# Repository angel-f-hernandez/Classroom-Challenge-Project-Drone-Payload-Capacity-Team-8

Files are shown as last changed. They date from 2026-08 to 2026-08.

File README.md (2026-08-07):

# Solution to Classroom Challenge Project Drone Payload Capacity and Structural Design Analysis

# Team
Ray Cillo (UCLA) - Project Manager, Quality Assurance

Angel Hernandez (Cal Poly SLO) - Documentation, Visualization & FEA Lead

Aadesh Bamane (SDSU) - Modeling Lead

Angelina Mikhaiel (SDSU) - Analysis/Validation Lead

# Project Details
In this project, a drone arm was designed and analyzed by calculating the maximum stress of the arm, performing a thrust-to-weight analysis to determine payload capacity, and conducting Finite Element Analysis. In designing the arm, our team first brainstormed simple shapes that could be used. After those shapes were sketched, their area, volume, and density equations were inputted into a MATLAB code, and dimensions were approximated before they were sketched and completed in a CAD software. This allowed us to pick dimensions for each arm that would keep it above our minimum factor of safety of 1.5 while still meeting the 0.5 kg minimum payload and 2:1 thrust-to-weight requirements. Finite element analysis would be completed after the shapes were sketched and designed in a CAD software. The two shapes that our team decided to use in this project are a hollow, oval shaped arm, and a truss inspired arm.

Our first set of dimensions came from the approximate MATLAB calculations, but the finite element analysis showed that those designs did not hold up. The oval arm deformed more than we wanted, and the truss arm fell below the minimum factor of safety for half of the material options, mostly because of stress concentrations at the joints and mounting holes that our simpler equations could not account for. We revised both designs with thicker walls and wider truss members, which fixed both problems but added mass and reduced how much payload the drone could carry.

After completing a MATLAB code to run a stress analysis and finite element analysis on each arm design, the two were compared to determine which design best met the requirements and stayed above the minimum factor of safety. Some of the factors that were considered when determining which design had the best results included which one had a better margin above the required factor of safety, and which one had the higher maximum payload capacity. The finite element analysis was also used to determine which arm design had less stress and displacement. These results can be seen in the graph and data below.

# Project Solution Instructions

**Requirements:** MATLAB R2023b or later with the Partial Differential Equation Toolbox.

1. Place the closed STL or STEP files for each drone-arm design in the `cad` folder.
2. Open `DroneDesign_StudentProjectTemplate.mlx` in MATLAB.
3. Update the `filePaths` string array so that it contains the relative path to each CAD file.
4. Update the `designNames` string array so that each design name corresponds to the CAD file in the same array position.
5. Update the `areas` array using units of square meters. In the current implementation, each value represents the surface area of one loaded face. The code assumes that all loaded faces selected for a design have equal areas, and the function multiplies this value by the number of selected loaded faces.
6. Run Task 1 to load the material properties and initialize the project parameters.
7. Run Task 3 to calculate the volume, arm mass, and maximum payload for each design and material combination.
8. Run the first portion of Task 4 containing `designVisualizer(filePaths)`. Use the displayed face labels to identify the attachment and load surfaces on each model.
9. Update `fixedFaces` with the face IDs of the surfaces attached to the drone body.
10. Update `loadedFaces` with the face IDs of the surfaces where the motor loads are applied.
11. Run the remainder of Task 4 to perform the finite element analyses, generate the displacement and von Mises stress plots, calculate the factor of safety, and create the final results table.
12. Review the results and confirm that the selected design:
* supports a payload of at least 0.5 kg,
* maintains a thrust-to-weight ratio of at least 2:1, and
* has a factor of safety of at least 1.5.
# Results
## Summary of Payload and FEA Results
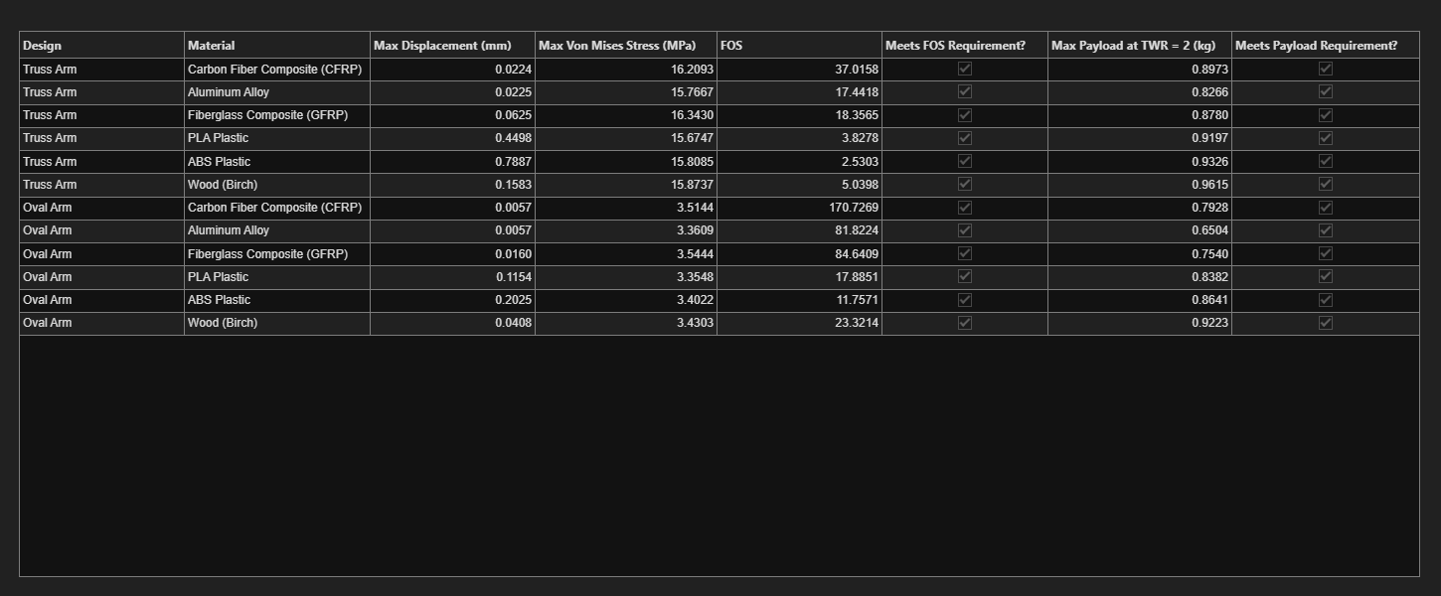
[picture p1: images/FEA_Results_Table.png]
Final table of results (task 4)


## Carbon Fiber Composite Planar Truss: Displacement and Von Mises Stress
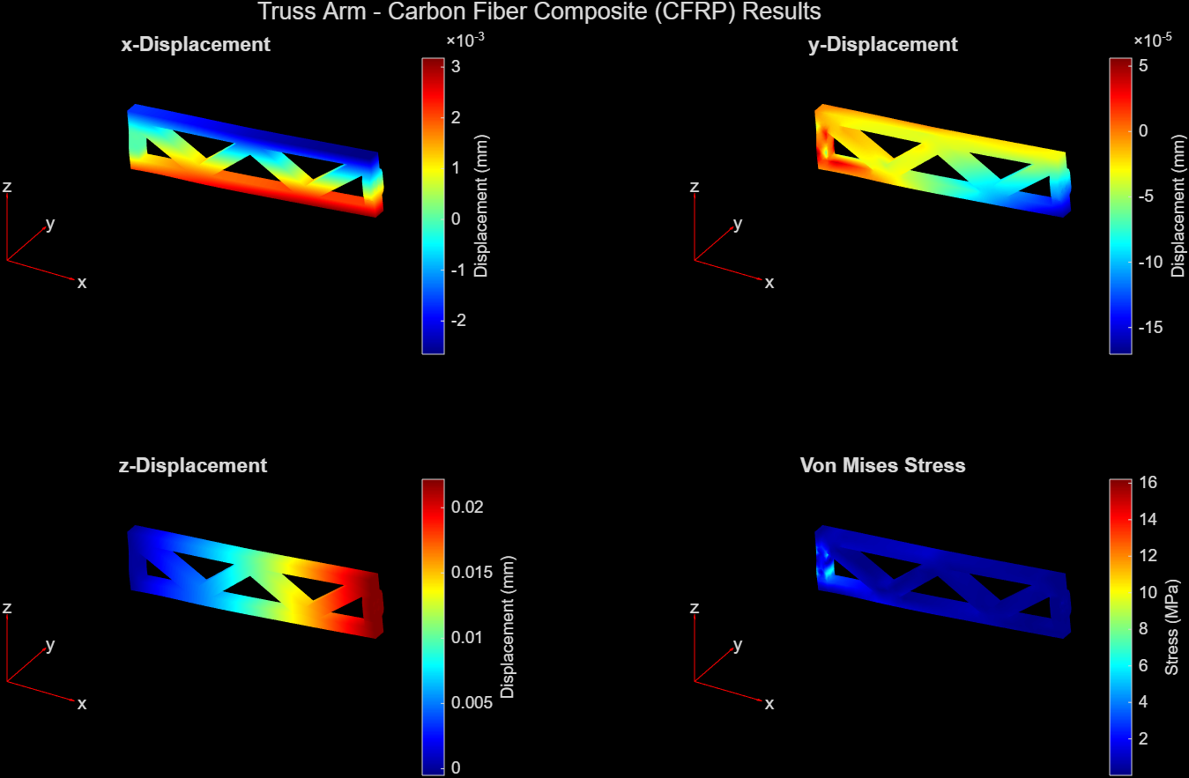
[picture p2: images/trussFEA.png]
FEA of truss (Carbon fiber)


## Carbon Fiber Composite Hollow Oval Arm: Displacement and Von Mises Stress
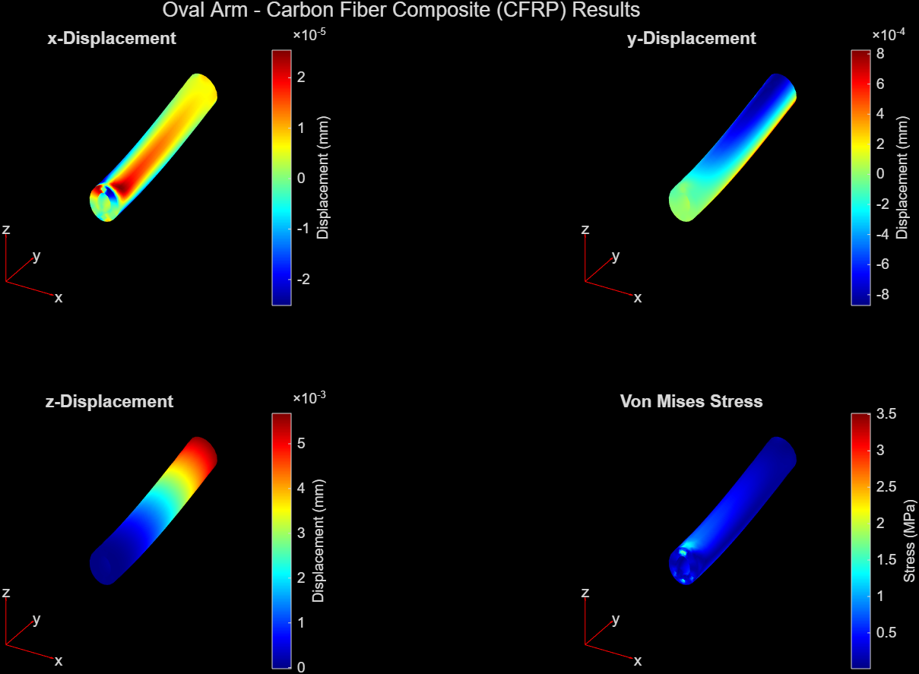
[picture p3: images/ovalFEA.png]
FEA of hollow oval (Carbon fiber)


# Final Recommendation

The recommended design is the planar truss arm made from carbon fiber composite. This combination supports a maximum payload of 0.8973 kg while limiting maximum displacement to approximately 0.0224 mm and maintaining a factor of safety above the required minimum of 1.5.

Although several lower-density materials provided slightly higher maximum payload capacities, they also experienced greater displacement. The carbon fiber truss therefore provided the best overall balance between payload capacity, stiffness, mass efficiency, and structural safety.
# Contact
raynittacillo@gmail.com

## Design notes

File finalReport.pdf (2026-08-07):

## Drone Payload Structure Design and Analysis

In this project, you are optimizing drone arm design, including geometry and material selection, to maximize payload capacity while ensuring structural integrity under motor-induced loads. You will use MATLAB to perform force balance analysis and finite element modeling to quantitatively support your design solution.

Use this Live Script as a template to get started on your project solution. You may include helper functions at the bottom of this document or as separate files. For a tutorial on how to use Live Scripts, check out this video. (https://www.youtube.com/watch?v=hUXTyPYRidM)

Suggested Tasks

1. Gather your starter assumptions and load the material properties into MATLAB.
2. Propose at least two drone arm designs
3. Perform a thrust-to-weight analysis to evaluate each of your designs across all material options. Your design must meet a minimum payload requirement and safety standards.
4. Perform finite element analysis across all design and material options.
5. Recommend a final design solution.

Table of Contents

## Break Down the Problem

In the space below, define the problem statement:

The goal is to design a drone arm that can safely handle motor-induced loads while maximizing payload capacity. Two structurally distinct designs must be created and analyzed using finite element analysis (FEA), thrust-to-weight analysis, and provided drone arm material properties. The designs must meet project-specified minimum payload and thrust-to-weight ratio requirements, as well as a minimum factor of safety (FOS) requirement to ensure safe operation.

List the requirements, constraints, and success criteria for the project:

Requirements:

- Minimum payload requirement: 0.5 kg
- Minimum thrust-to-weight ratio: 2:1
- Minimum FOS: 1.5

Constraints:

- Quadcopter configuration: 4 motors and 4 propellers
- Motor mass: 0.065 kg per motor
- Thrust per motor: 1 kg of thrust
- Maximum total thrust: 4 kg of thrust
- Maximum drone arm mass: 0.125 kg per arm
- Total mass of components excluding drone arms and payload: 1.0 kg

Success Criteria:

1. Drone arm must maximize payload capacity while meeting minimum thrust-to-weight ratio and minimum FOS.
2. Drone arm must minimize mass.
3. Drone arm must limit maximum stress and displacement.
4. Drone arm should minimize material cost (optional).

What is your proposed solution?

We propose two possible drone arms. The first drone arm design will use a hollow oval cross-section
and one drone body attachment points. The second drone arm will use a triangular truss design and contain three drone body attachment points, and the truss design will contain solid outer supports and solid inner web members.

List the steps you will need to take to achieve your proposed solution:

1. Sketch out two drone arms, making sure to include rough dimensions, a motor attachment point, and drone body attachment point(s).
2. Create the 3D models from sketches using CAD software. Export these models as STL for analysis.
3. Analyze both drone arms and provide initial thrust-to-weight ratio results for each drone arm and material combination.
4. Perform FEA on the drone arms and record x-, y-, and z- displacement as well as Von Mises stress. Ensure drone arms meet the minimum FOS.
5. Use an optimization function that minimizes mass and material cost (optional).
6. Display required results. This includes thrust-to-weight and FEA results for each drone arm and material combination.
7. Analyze the FEA data and compare the advantages/disadvantages of each drone arm. Comparison should include payload capacity, arm mass, FOS, Von Mises stress, and displacement differences.
a. Optional: Include material cost comparison.
8. Submit our final report which includes a drone arm design recommendation.

What challenges do you face in the process of achieving the solution?

1. Material selection and tradeoff analysis: Each material has different properties that give it distinct advantages and disadvantages. The challenge arises from selecting a material with advantageous properties that align with the drone arm requirements while minimizing disadvantageous properties.
2. Drone arm design and CAD: The dimensions of the drone arm affect mass, stress, and displacement, which makes dimension selection a vital part of the drone design process. Additionally, the selected dimensions must be realistic to ensure that the drone arm can be manufactured. Due to the team's limited experience in design, the selection of proper dimensions is a challenge.
3. FEA setup: The team members have limited experience with FEA. As a result, properly setting up FEA in MATLAB and accurately interpreting results becomes a challenge.

## Task 1: Gather your starter assumptions and load material properties

Load the provided droneArmMaterials.mat file into MATLAB. This contains a data struct with the material properties for six different materials commonly used for drones (carbon fiber composite, aluminum alloy, fiberglass composite, PLA plastic, ABS plastic, and wood). For each material, you have been provided the following information:

▪
Density ( ), in
- Young's Modulus (E) in Pa
- Poisson's ratio ( ), unitless
- Yield strength, in Pa
- Average cost per meter in US dollars

For this project, you can assume the following design parameters:

- Quadcopter drone with 4 motors and 4 propellers
- Each motor can provide up to 1kg thrust
▪
Acceleration due to gravity:
- Total weight of the drone components without the arms or the payload: 1kg

The breakdown of the weight of each drone component is as follow:

- Battery = 0.3kg
- Each motor = 65g, 4 motors = 0.26kg
- Each propeller = 10g, 4 propellers = 0.04 kg
- Each electronic speed controller = 30g, 4 electronic speed controllers = 0.12 kg
- Flight controller and electronics = 0.05kg
- Receiver/GPS = 0.03kg
- Drone frame (center body) excluding arms = 0.2kg

clear, clc, close all
addpath('functions');
materials = importdata("data\droneArmMaterials.mat");

% Assign file paths for drone arm files filePaths = [
"cad/TrussArm.step"
"cad/OvalArm.step"
];
designNames = [
"Truss Arm"
"Oval Arm"
];
areas = [[0.00002827, 0.00002827]]; % m^2

% Arrays of material data

[materialNames, density, youngsModulus, poissonsRatio, yieldStrength, cost] = materialDataExtractor(materials);
nMaterials = numel(materials);
g = 9.81; | % gravitational acceleration [m/s^2]
nMotors = 4; | % number of motors
nProps = 4; | % number of propellers
nArms = 4; | % number of arms

thrustPerMotor_kg = 1;
maxTotalThrust_kg = nMotors * thrustPerMotor_kg;
mBattery = 0.30; | % battery [kg]
mMotors = nMotors * 0.065; % 4 motors, 65 g [kg]
mProps = nProps * 0.010; | % 4 propellers, 10 g [kg]
mEsc = 4 * 0.030; | % 4 ESCs, 30 g [kg]
mFlightCtrl = 0.05; | % flight controller + electronics [kg]
mReceiverGPS = 0.03; | % receiver / GPS [kg]
mFrame = 0.20; | % center body, excludes arms [kg]

baseMass = mBattery + mMotors + mProps + mEsc + mFlightCtrl + mReceiverGPS + mFrame;

motorMass = 0.065; % [kg]

minPayload = 0.5; | % minimum required payload [kg]
minTWR = 2; | % minimum thrust-to-weight ratio
minFOS = 1.5; | % minimum factor of safety

% Net transverse tip load for the Task 3 stress pre-screen [N] thrustPerMotor_N = thrustPerMotor_kg * g;
motorWeight_N = motorMass * g;
F_tip_N = thrustPerMotor_N - motorWeight_N; | % net upward load bending the arm
FOSmin_preFEA = 2.0; | % FOS accounting for hand calculation
errors

## Task 2: Propose at least two drone arm designs

Develop at least two distinct drone arm designs by drawing clear, neatly labeled sketches that show key geometric features, including:

- Overall shape (e.g. beam, tube, truss structure)
- Dimensions (length, width, thickness)
- Motor mount location
- Where the arm connects to the drone body

The two designs should be meaningfully different from each other (e.g. different geometries or structural strategies) and not just small variations of the same idea.

Navigate to the 'Insert' tab and insert pictures of your sketches in the space below (hand-drawn or digital). Include a short design description for each sketch that includes:

- Geometry (e.g. solid beam, hollow tube, beam with trusses)
- Why you chose this design
- How it might perform under load

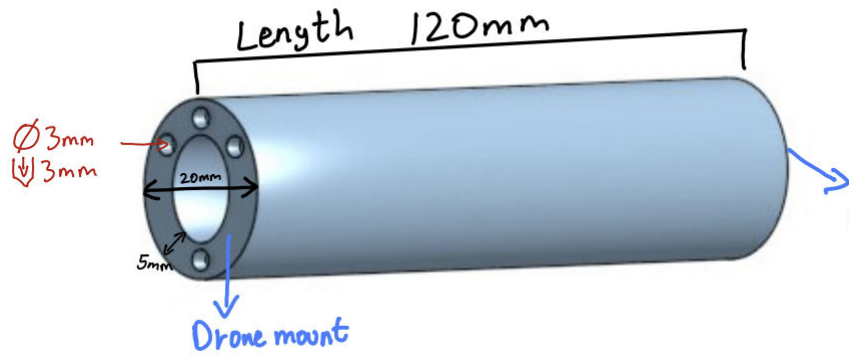
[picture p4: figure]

Design 1 — Hollow Oval Tube

Geometry: Hollow oval tube, 120 mm long, 25 mm tall × 20 mm wide outer cross-section with a 5 mm uniform wall (15 × 10 mm inner bore). Motor mounts at the tip via four Ø3 mm × 3 mm holes; the arm bolts to the drone body at the base end through a matching four-hole pattern.

Why we chose it: A closed section distributes bending load around the full perimeter and resists torsion from motor and propeller reaction, which an open section cannot. Hollowing the center removes material near the neutral axis, where bending stress is lowest, so very little strength is given up for the weight saved. The section is taller than it is wide because section depth is cubed in the second moment of area while width contributes only linearly, so the tall orientation resists bending far better at the same mass.

How it performs under load: Acts as a cantilever beam, with stress peaking at the top and bottom outer surfaces where the arm meets the body. Our initial design used a thinner wall, but FEA showed excessive tip deflection, which we judged too flexible for stable flight. Increasing the wall to 5 mm brought deflection down substantially at the cost of additional mass.

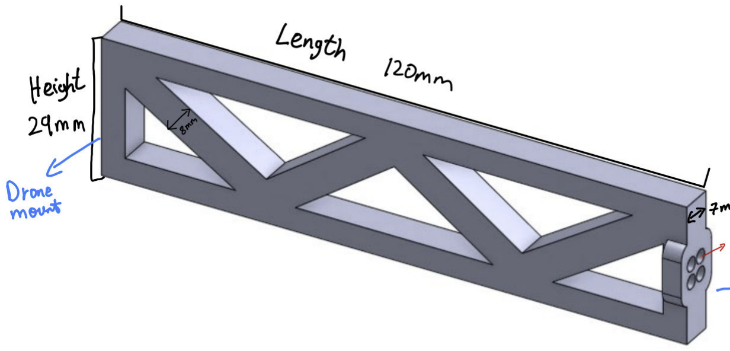
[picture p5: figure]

Design 2 — Planar Truss

Geometry: Flat truss plate, 120 mm long, 29 mm tall, 7 mm thick, with 8 mm wide members forming triangular bays. Motor mounts at the tip through four Ø3 mm × 3 mm holes in a raised boss; the base end attaches to the drone body across the full-height end face.

Why we chose it: Inspired by bridge trusses, which achieve high strength per unit weight. The triangular pattern removes material from regions carrying little load while keeping material along the top and bottom edges where bending demand is highest, so the arm occupies a large structural envelope while using far less material than a solid beam of the same size.

How it performs under load: Bending is resolved into a tension–compression couple in the top and bottom chords, with the diagonals carrying shear between them. Our initial design used 3 mm members, but FEA showed factor of safety below the 1.5 requirement for several material options, driven by stress concentrations at the joints that our analytical model did not capture. Widening the members to 8 mm resolved this across all six materials.

## Task 3: Perform thrust-to-weight analysis across all design and material options

Write a MATLAB function that will perform a thrust-to-weight analysis across all design and material options. This analysis will help you evaluate which drone arm design and which material optimizes payload capacity while meeting suggested safety requirements.

- Your design must support a minimum payload of 0.5kg.
- Your design must meet a thrust-to-weight ratio of at least 2:1 to ensure safe and stable flight. This safety standard is widely used in drone design. Conceptually, it means that the drone's maximum thrust must be at least twice its weight. This ensures stable hovering and maneuvering with a safety margin. Note that the thrust-to-weight safety margin is a system-level safety standard for drone flight that is distinct from the structural safety factor of the drone arms (which you will evaluate later through finite element analysis).
- Your goal is calculate maximum payload capacity for each design and material option (i.e. what is the heaviest payload your drone design could carry while still allowing the drone to safely take off?)

Ensure that the results of your analysis can be readily interpreted, e.g. in the form of a summary table or plot.

Note: if you have two drone arm designs, the expected output should be 12 payload capacity estimates (2 designs across 6 materials options).

% Calculate the volumes of each design (m^3 * kg/m^3)
volumes = calculateDesignVolume(filePaths);

% calculate the mass for each combination of material and design
armMass = density * volumes; | % kg
totalArmMass = armMass .* nArms; | % kg

% calculate max allowed mass and total mass
maxAllowedMass = maxTotalThrust_kg / minTWR; | % kg
totalMass = totalArmMass + baseMass; | % kg

% Calculate max payload
maxPayload = maxAllowedMass - totalMass; | % kg

% Check to see if material and design combination meets the requirements meetsRequirementMinPayload = maxPayload >= minPayload;

## Task 4: Perform finite element analysis across all design and material options

Perform finite element analysis (FEA) across all design and material options to evaluate the structural safety factor of your drone arm design. To simplify the task, you will perform the FEA only on a single drone arm.

Using a CAD software of your choice, first create a 3D model of one drone arm for each of your designs. Be sure your model can be exported as a STEP or STL file for analysis in MATLAB.

- Recommended CAD software options: Tinkercad, Onshape, Fusion 360, Solidworks (most have free versions)

Import your model into MATLAB and perform FEA. In your FEA model, you should model and apply two loads to the drone arm: upward thrust force from the motor and downward weight of the motor.

- Helpful resources: online tutorial, (https://matlabacademy.mathworks.com/details/introduction-to-finite-element-analysis-with-matlab/otmlfea) documentation for Structural Mechanics (https://www.mathworks.com/help/pde/structural-mechanics.html) and Partial Differentiation Equation Toolbox, (https://www.mathworks.com/help/pde/index.html?s_tid=CRUX_lftnav) and example workflow (https://www.mathworks.com/help/pde/ug/deflection-analysis-of-bracket-femodel.html)

For each design and material combination, you should report the overall maximum displacement, maximum stress, and factor of safety and include visualizations of the x-, y-, and z-displacement and Von Mises stress. Ensure that your results are presented for easy interpretation (e.g. present a table with numerical results, clearly labeled subplots for the visualizations).

- The factor of safety compares how strong a material is to how much stress it experiences, indicating whether
a design is safe under the given loads. For this project use the equation: | .

Yield strength indicates how much stress a given material can withstand before permanently deforming. Maximum von Mises stress (derived from your FEA model) is a measure of how much stress your design experiences under the applied loads.
- A typical engineering safety margin for FoS is ~1.5-2+
- This example (https://www.mathworks.com/help/pde/ug/deflection-analysis-of-bracket-femodel.html) demonstrates the plots you are asked to include in your results

% Runs design visualizer to determine which faces a re fixed and loaded designVisualizer(filePaths)

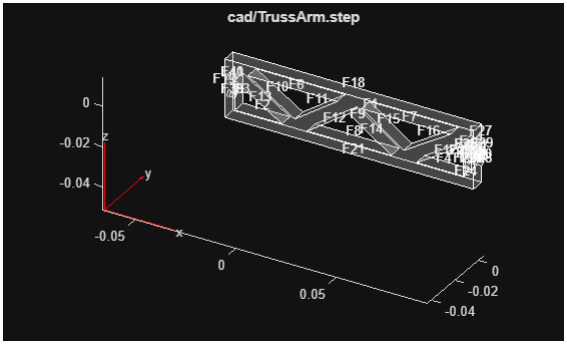
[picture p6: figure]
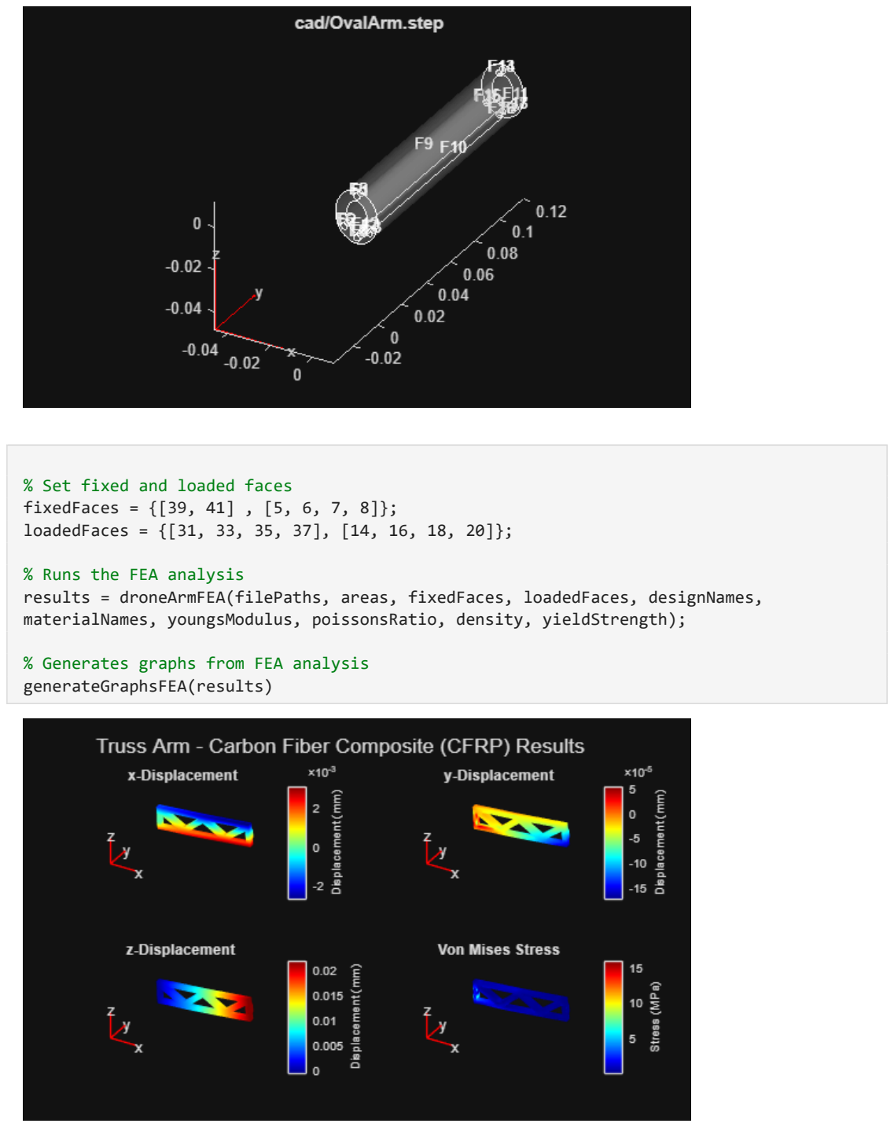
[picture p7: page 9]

% Set fixed and loaded faces
fixedFaces = {[39, 41] , [5, 6, 7, 8]};
loadedFaces = {[31, 33, 35, 37], [14, 16, 18, 20]};

% Runs the FEA analysis
results = droneArmFEA(filePaths, areas, fixedFaces, loadedFaces, designNames, materialNames, youngsModulus, poissonsRatio, density, yieldStrength);

% Generates graphs from FEA analysis
generateGraphsFEA(results)

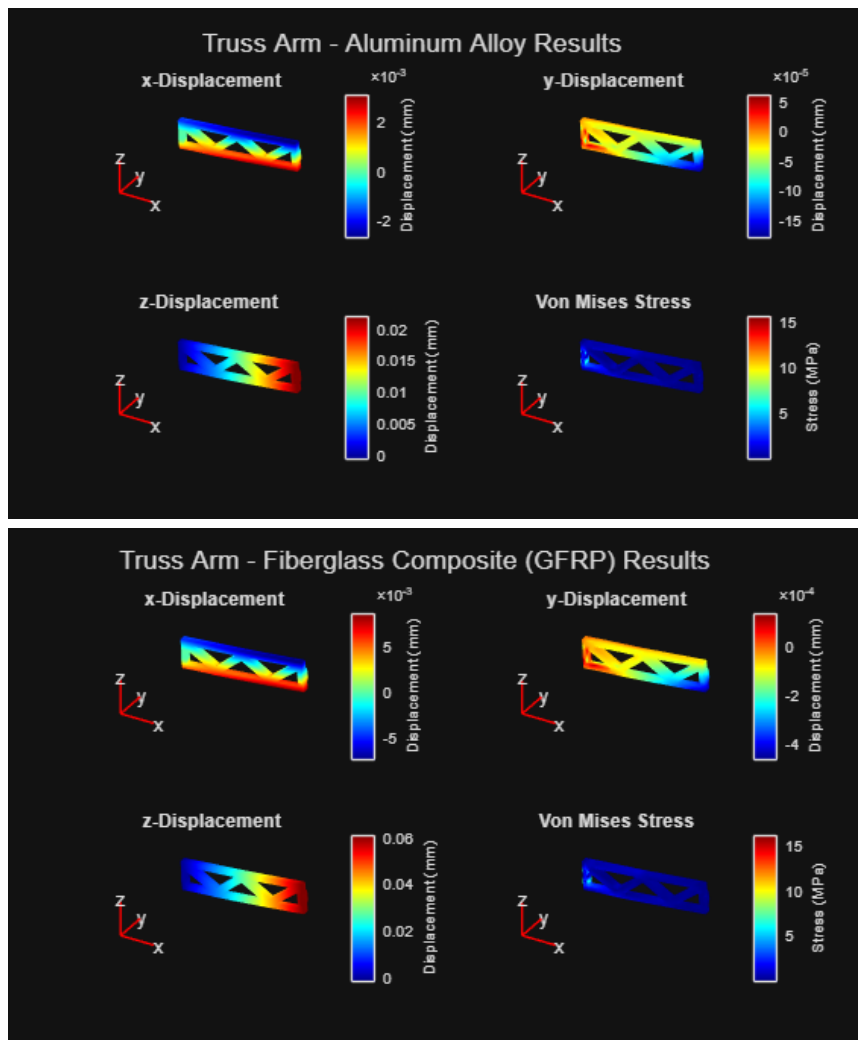
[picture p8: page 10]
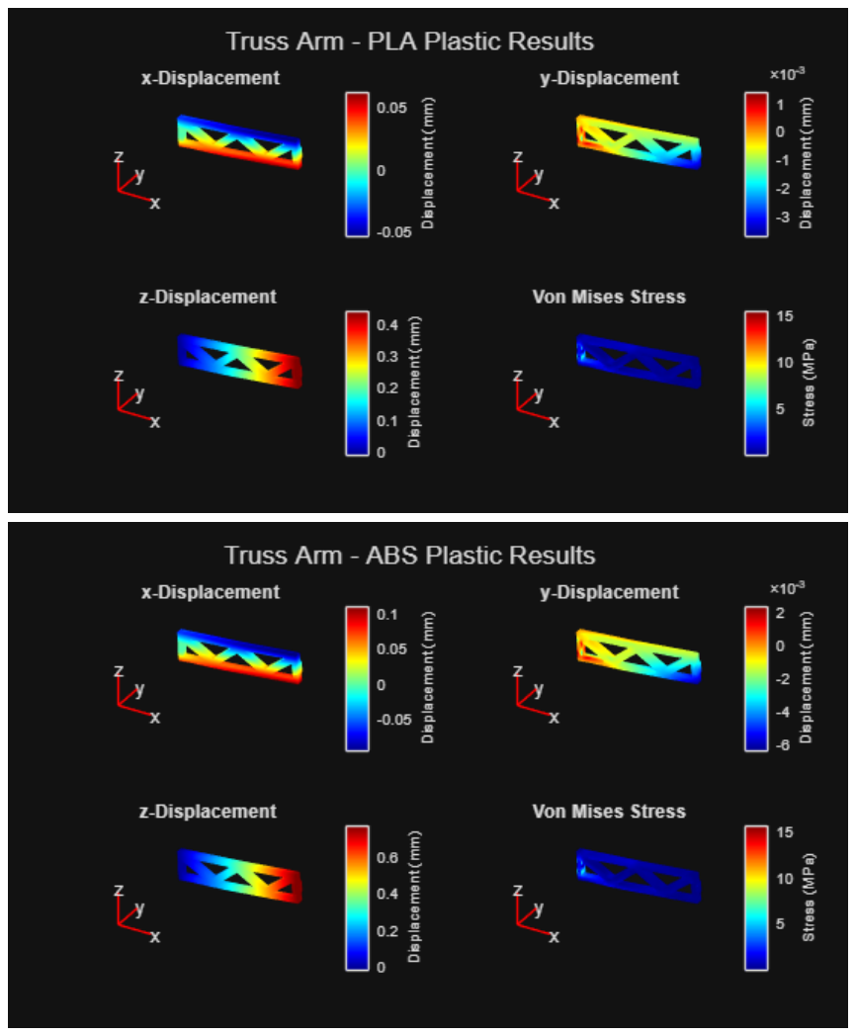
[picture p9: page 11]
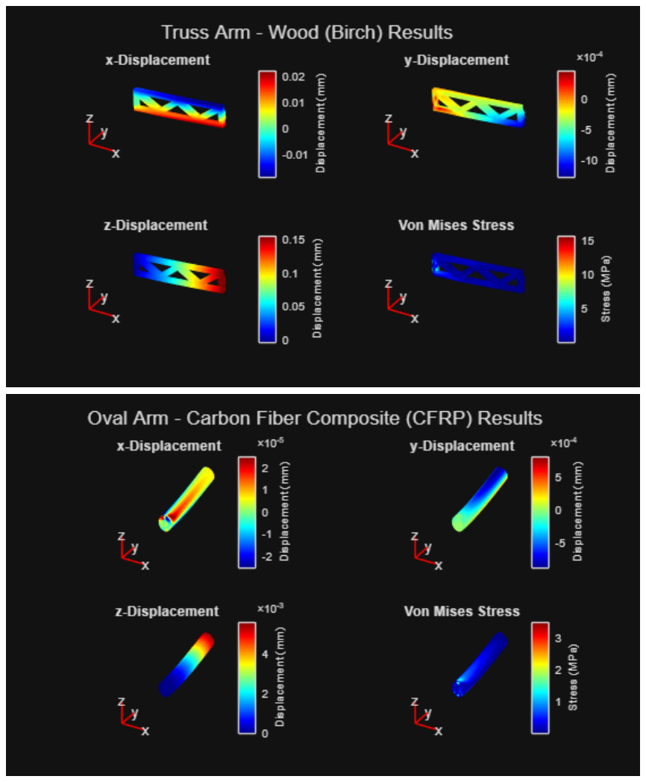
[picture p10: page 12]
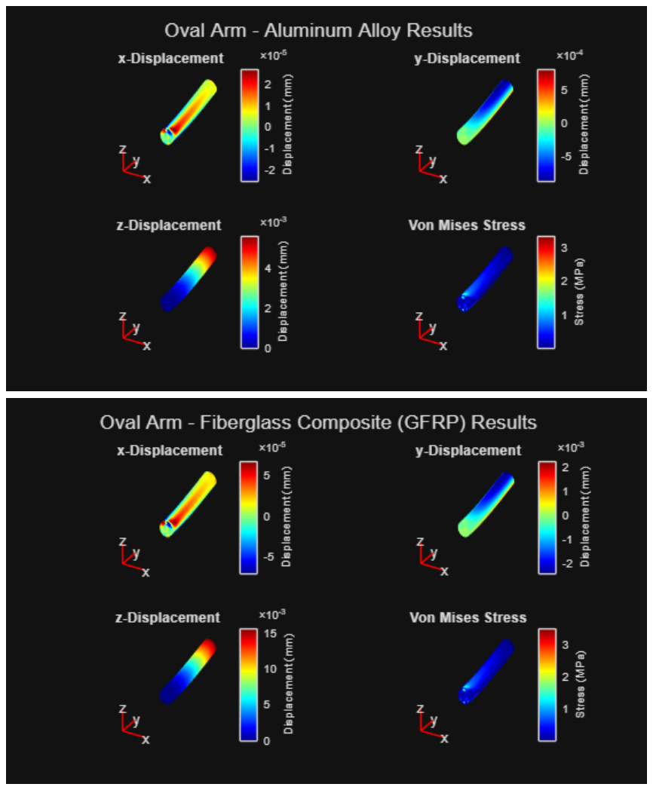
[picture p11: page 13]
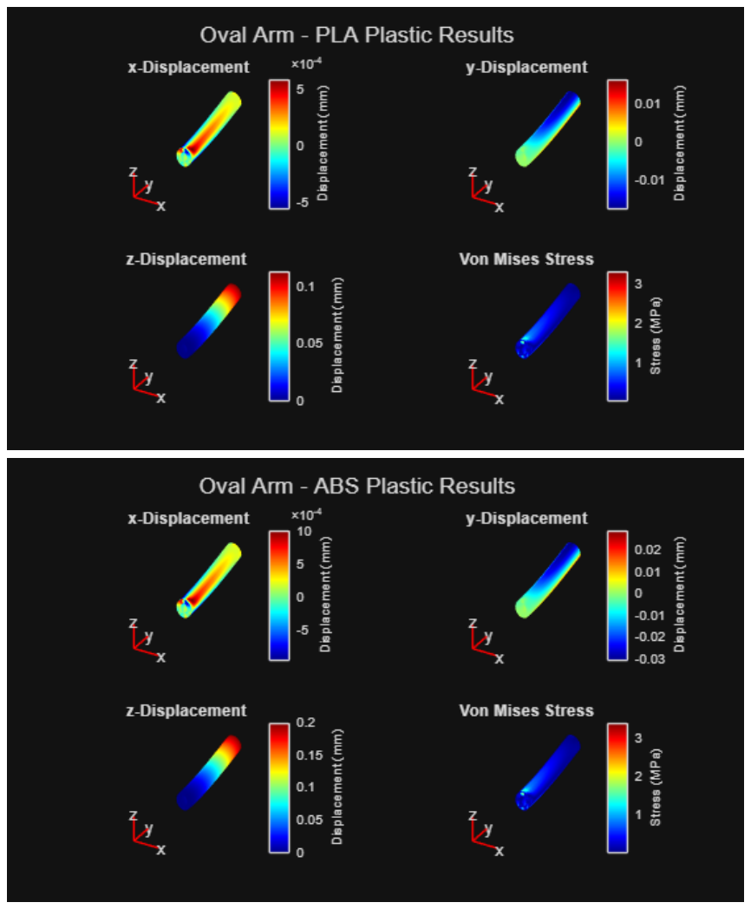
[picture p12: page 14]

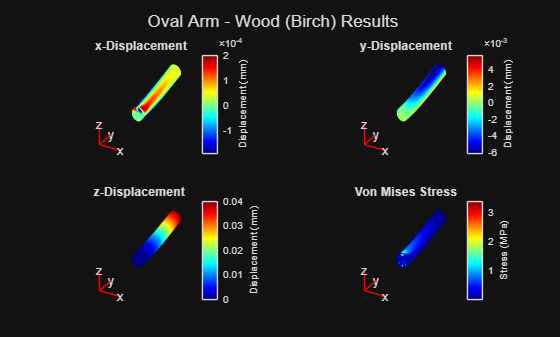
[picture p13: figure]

% Generates final results table

designNameColumn = vertcat(results.DesignName);
materialNameColumn = vertcat(results.MaterialName);
maxDisplacementColumn = vertcat(results.MaximumDisplacement) * 1000; maxVonMisesStressColumn_MPa = vertcat(results.MaximumVonMisesStress) ./ 1e6; FOSColumn = vertcat(results.FOS);
meetsFOSColumn = FOSColumn >= minFOS;
maxPayloadColumn = reshape(maxPayload, [], 1);
meetsPayloadColumn = reshape(meetsRequirementMinPayload, [], 1);

finalResults = table( ...
designNameColumn, ...
materialNameColumn, ...
maxDisplacementColumn, ... maxVonMisesStressColumn_MPa, ... FOSColumn, ...
meetsFOSColumn, ...
maxPayloadColumn, ...
meetsPayloadColumn);
finalResults.Properties.VariableNames = ["Design" "Material" "Max Displacement (mm)" "Max Von Mises Stress (MPa)" "FOS" "Meets FOS Requirement?" "Max Payload at TWR = 2 (kg)" "Meets Payload Requirement?"];

% Creates uifigure to display results table
resultsFig = uifigure( ...
'Name', 'Design Comparison Results', ... 'Position', [100 100 1450 600]);

resultsTable = uitable(resultsFig, ... 'Data', finalResults, ...

'Position', [20 20 1410 550]);
% Exports the image to pre-selected directory exportapp(resultsFig, "images/FEA_Results_Table.png");


## Interpretation of Results - Final Recommended Design Solution

Using the results of your thrust-to-weight analysis and finite element analysis, recommend a final drone arm design that meets all required constraints. Your recommendation should clearly identify the selected design (arm geometry and material choice), make use of quantitative results to justify your decisions, demonstrate that the design meets the constraints, explain the trade-offs considered, and include comparisons to alternative designs.

Approach and Methodology:

Two drone arms are proposed as a possible solution to this project, a planar truss design and a hollowed oval design. Each design and material combination was first checked to ensure that it could meet the minimum thrust-to-weight ratio (TWR) of 2:1 while also allowing for a minimum payload of 0.5 kg.

Finite element analysis (FEA) was then performed on each combination of drone arm designs and materials to determine maximum displacement, maximum Von Mises stress, and factor of safety (FOS). The minimum requirements for this project are a FOS of 1.5 and a payload capacity of 0.5 kg.

Results and Analysis:

After running the FEA simulation on every combination of arm design and material, all combinations satisfied both the payload and factor-of-safety requirements.

The design with the lowest payload capacity was still able to support approximately 0.6504 kg, which is
30.0% greater than the required minimum payload of 0.500 kg. Likewise, every design exceeded the minimum required FOS of 1.5, with the lowest calculated FOS being approximately 2.53.

Because every design satisfied the minimum requirements, the final recommendation was based on which combination provided the best overall balance of payload capacity, structural stiffness, arm mass, and safety margin.

The standout result was the planar truss design made from carbon fiber composite. It supported a maximum payload of 0.8973 kg while maintaining excellent structural stiffness, with a maximum displacement of only 0.0224 mm. Although the PLA plastic, ABS plastic, and wood versions of the planar truss supported slightly higher maximum payloads, they experienced greater displacement. In contrast, the hollow oval arm designs generally exhibited greater stiffness, but their higher mass resulted in lower payload capacities. This indicates that the carbon fiber truss provides a strong overall balance between payload capability, structural rigidity, and mass efficiency.

Challenges Encountered:

The biggest challenge in this project was defining the boundary conditions for the FEA model. The imported CAD geometries contained many individual faces, which made it difficult to correctly identify the fixed and loaded surfaces. As a result, multiple simulations had to be performed to verify that the selected boundary conditions produced realistic displacement and stress behavior.

Determining the surface area of the selected loaded faces was also challenging. There was no straightforward method in our workflow to automatically calculate the surface area of the specific selected faces. To address this, the required face areas were obtained from the CAD software and then manually incorporated into the MATLAB code for the traction calculations.

Design Decisions and Trade-offs:

The final design selection required balancing several competing factors, including payload capacity, structural stiffness, mass, and factor of safety. No single design performed best in every category, so the final recommendation was based on overall performance rather than one isolated metric.

The planar truss geometry was favored because it reduced unnecessary material while maintaining a strong load path between the motor mount and the drone body. This lower mass improved payload capacity compared with the hollow oval design. However, the hollow oval arms generally exhibited lower displacement, indicating greater stiffness under the same loading conditions.

Material selection involved a similar trade-off. PLA plastic, ABS plastic, and wood allowed the planar truss to carry slightly greater payloads than carbon fiber because of their lower densities. However, those materials also experienced larger displacements. Carbon fiber composite provided a stronger balance between low mass and stiffness, supporting a payload of 0.8973 kg while limiting maximum displacement to only 0.0224 mm.

Although some alternative designs achieved either a higher payload capacity or lower displacement, the carbon fiber planar truss performed well in both categories while also exceeding the minimum factor-of-safety requirement of 1.5. For this reason, the carbon fiber composite planar truss was selected as the final recommended design because it provides the best overall compromise between payload capacity, structural rigidity, mass efficiency, and safety.

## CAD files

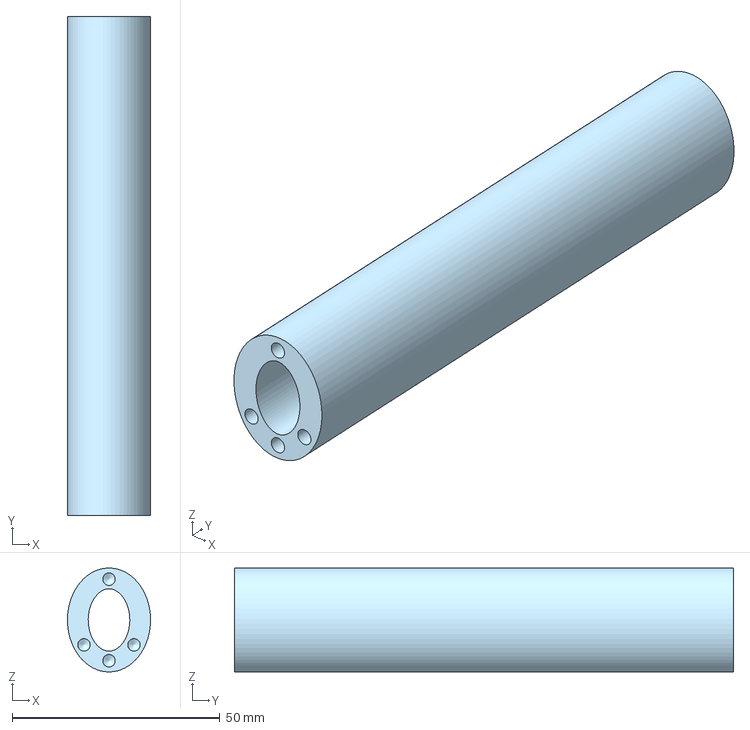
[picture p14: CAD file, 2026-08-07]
cad/OvalArm.step
20.0 x 120.0 x 25.0 mm

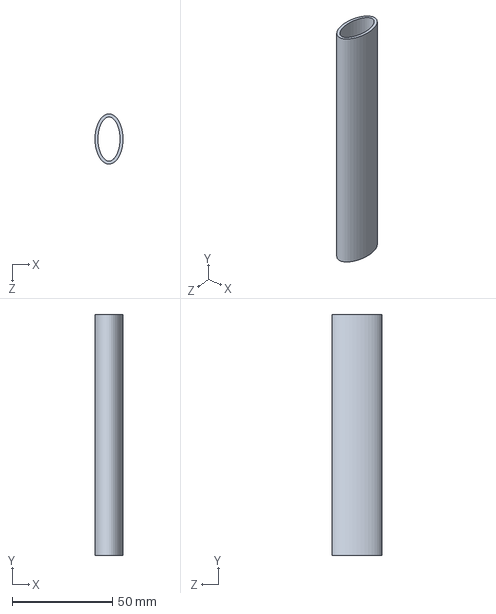
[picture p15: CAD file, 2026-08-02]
SolidWorks/OvalArmpart.SLDPRT
14.0 x 120.0 x 25.0 mm

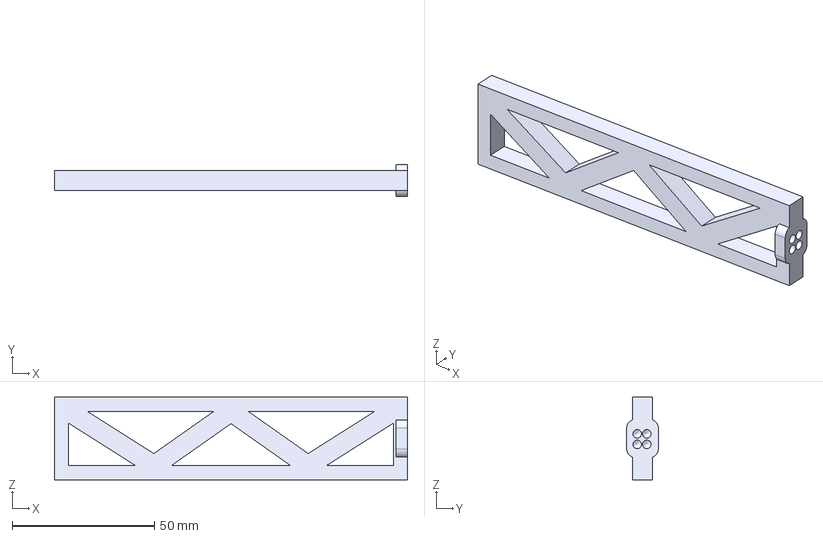
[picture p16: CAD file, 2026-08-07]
cad/TrussArm.step
124.0 x 11.1 x 29.0 mm

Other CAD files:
SolidWorks/OvalArm.STL
SolidWorks/TrussArm.SLDPRT
SolidWorks/TrussArm.STL

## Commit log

2026-07-13 Created main program insertion point
2026-07-16 Create droneArmCalculations
    Computes maximum payload and cost for different drone arm dimensions, shapes, and materials.
2026-07-16 Add files via upload
    Computes the cost and maximum payload for an arm given the dimensions, material, and shape of the arm. To use, type droneArmCalculations(materials) into the command window and follow the prompts.
2026-07-16 Update to camel case
2026-07-20 Create functions that perform FEA on CAD file as well as ouputs graphs detailing x-, y-, and z- displacement and Von Mises stress
2026-07-22 arm analysis function + volume helper functions
2026-07-22 arm analysis + volume functions
2026-07-27 Add files via upload
    changed stl units to meters
2026-08-01 Added STL files for drone arm
    [OvalArm.STL, TrussArm.STL]
2026-08-02 Complete FEA workflow, add volume and debug tools, and update sections 3–4
    [OvalArm.STL, TrussArm.STL]
2026-08-05 Updated droneArmFEA.m, designVisualizer.m, README.md, and DroneDesign_StudentProjectTemplate.mlx. Uploaded updated drone arm designs
    [OvalArm.STL, ThickOvalArm.stl, ThickTrussArm.stl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]
2026-08-07 Add STEP exports for oval and truss arms
    [ThickOvalArm.step, TrussArm.step]
2026-08-07 Update FEA simulation confoguration and delete old drone arm designs
    [OvalArm.step, ThickOvalArm.stl, ThickTrussArm.stl]
